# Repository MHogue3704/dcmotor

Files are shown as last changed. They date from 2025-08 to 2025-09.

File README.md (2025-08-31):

# ESP32 DC Motor Controller with OLED Interface

This project is a sophisticated motor controller for a 12V DC motor, built using an ESP32 microcontroller. It features a user-friendly interface with an SH1106 OLED display and a rotary encoder for precise speed adjustments, making it ideal for applications requiring fine-tuned motor control.

## Features

*   **Precise Speed Control:** Utilizes PWM to adjust the motor's speed from 0% to 100%.
*   **OLED Display Interface:** A 1.3-inch SH1106 OLED screen displays the motor's status (ON/OFF) and current speed.
*   **Rotary Encoder Input:** A rotary encoder with a push-button allows for intuitive speed adjustments and control.
*   **Save & Revert Speed Settings:** A "Confirm" button saves the desired speed, while a "Back" button reverts to the previously saved setting.
*   **Robust Motor Driver:** Employs the L298N H-Bridge to safely and efficiently drive the DC motor.
*   **Built with PlatformIO:** The project is configured for the PlatformIO IDE, ensuring easy dependency management and compilation.

## Hardware Components

| Component | Purpose |
| --- | --- |
| ESP32 Development Board | Main microcontroller for logic and control. |
| L298N H-Bridge Motor Driver | Drives the high-current DC motor. |
| 12V DC Geared Motor (e.g., 3 RPM) | The motor being controlled. |
| SH1106 1.3" OLED Module with Encoder | User interface for display and input. |
| CA-1235 Buck Converter Module | Steps down 12V to 5V for the ESP32. |
| 12V DC Power Supply | Powers the L298N driver and the motor. |
| Jumper Wires | For making connections. |

## Wiring Instructions

This project requires wiring for both the motor driver and the OLED display module. Detailed, step-by-step guides for each are provided in the repository:

*   **For the L298N Motor Driver:** Please refer to the [**`WIRING.md`**](./WIRING.md) file.
*   **For the SH1106 OLED Module:** Please refer to the [**`OLED_WIRING.md`**](./OLED_WIRING.md) file.

**Crucial:** Ensure you have a common ground (`GND`) connection between the ESP32-C3, the L298N module, and the OLED module for stable operation.

## Software Setup & Installation

This project is managed using PlatformIO.

1.  **Install PlatformIO:** If you haven't already, install [PlatformIO IDE for VS Code](https://platformio.org/install/ide?install=vscode).
2.  **Clone the Repository:**
    ```bash
    git clone https://github.com/MHogue3704/dcmotor.git
    cd dcmotor
    ```
3.  **Open in PlatformIO:** Open the cloned folder in VS Code with the PlatformIO extension installed.
4.  **Build & Upload:** PlatformIO will automatically detect the `platformio.ini` file and download the required libraries (`U8g2`, `RotaryEncoder`, `OneButton`). Once the dependencies are installed, build and upload the project to your ESP32.

## How to Use

Once the hardware is wired and the firmware is uploaded, the controller is ready to use:

1.  **Power On:** Connect the ESP32 via USB and turn on the 12V power supply for the motor.
2.  **View Display:** The OLED screen will light up, showing the motor status and speed.
3.  **Adjust Speed:** Turn the rotary encoder knob to increase or decrease the motor speed. The display will show `(Unsaved)` to indicate the change is temporary.
4.  **Save Speed:** Press the **"Confirm"** button to save the new speed. The `(Unsaved)` message will disappear.
5.  **Revert Speed:** If you make an adjustment you don't want, press the **"Back"** button to revert to the last saved speed.
6.  **Toggle Motor:** Click the **rotary encoder's built-in button** to toggle the motor ON or OFF.

## Code Overview

The main logic is contained in `src/main.cpp`:

*   **Pin Definitions:** All GPIO pin assignments for the motor and OLED module are at the top of the file.
*   **`setup()`:** Initializes serial communication, pin modes, PWM channels, the OLED display, and button handlers.
*   **`loop()`:** Continuously checks for input from the encoder and buttons.
*   **`drawScreen()`:** Renders the user interface on the OLED display.
*   **`updateMotor()`:** Applies the current speed value to the motor via PWM.
*   **Input Handlers (`checkEncoder`, `handle...Click`)**: These functions process input from the rotary encoder and buttons to modify the motor's state.




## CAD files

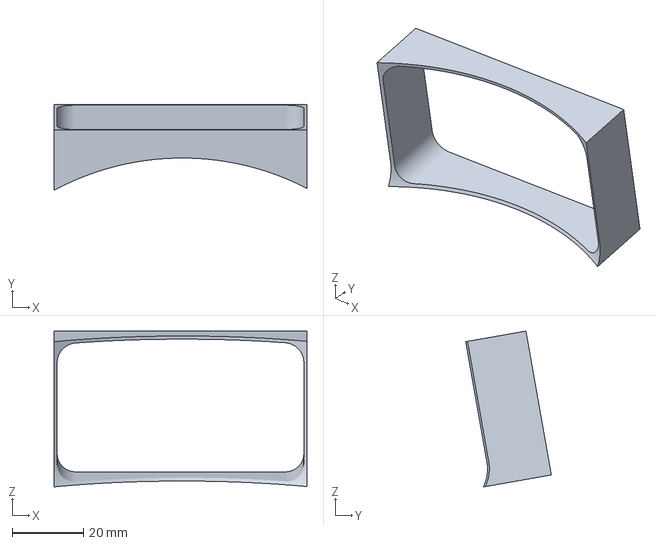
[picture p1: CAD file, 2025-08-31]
stl/controlbox.3mf
71.0 x 24.0 x 43.7 mm

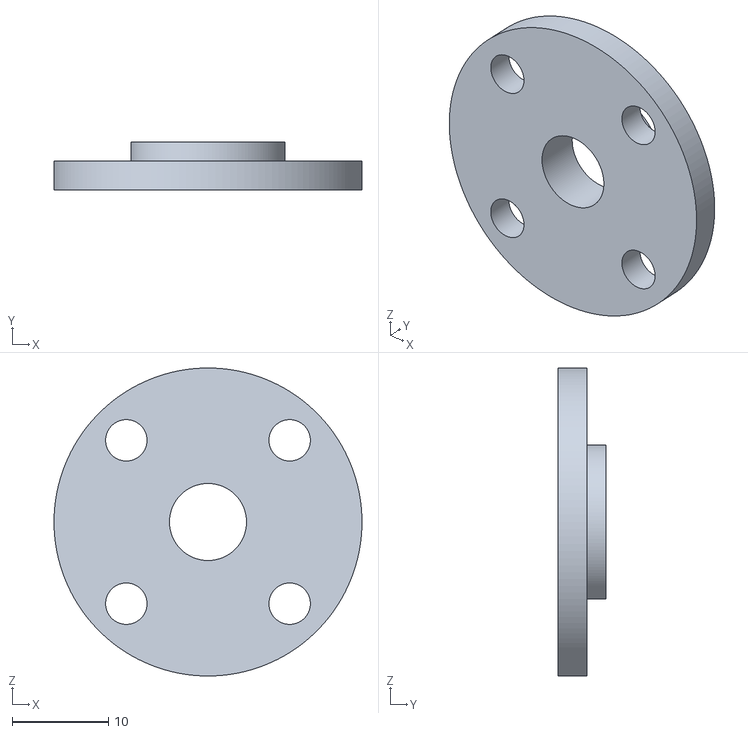
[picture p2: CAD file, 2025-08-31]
stl/Top_Cnter_Cap.stl
32.0 x 5.00 x 32.0

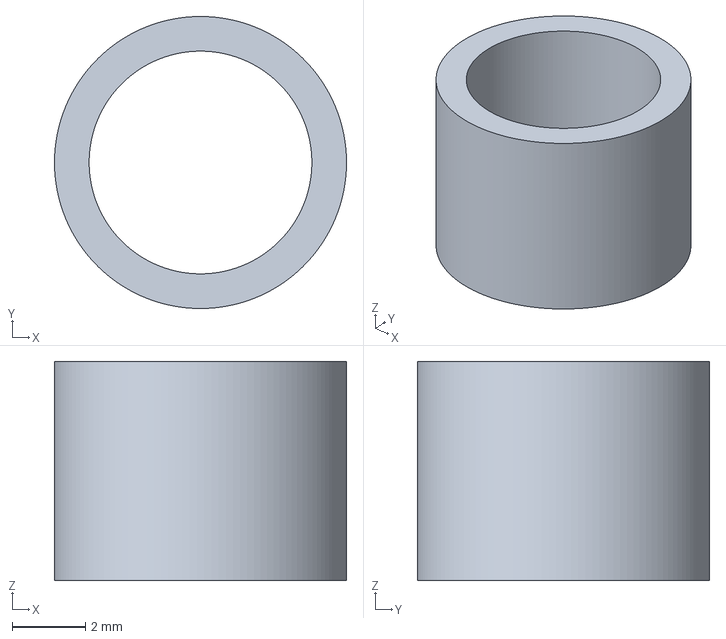
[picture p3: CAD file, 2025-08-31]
stl/motorbushing.3mf
8.00 x 8.00 x 6.00 mm

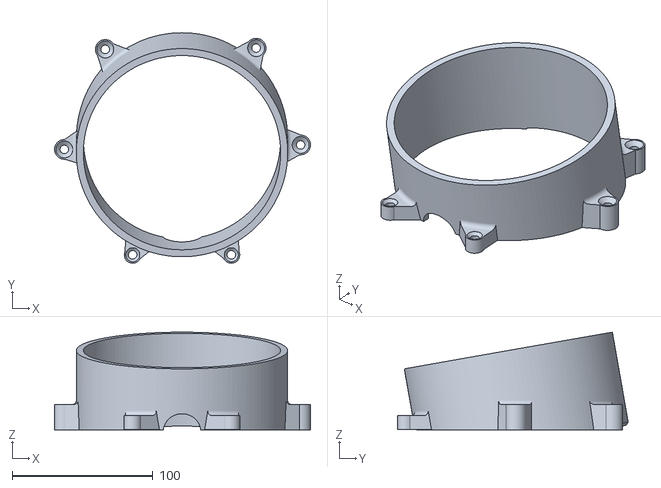
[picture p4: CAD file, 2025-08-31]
stl/CaseBottomV2.stl
181.7 x 163.6 x 69.3

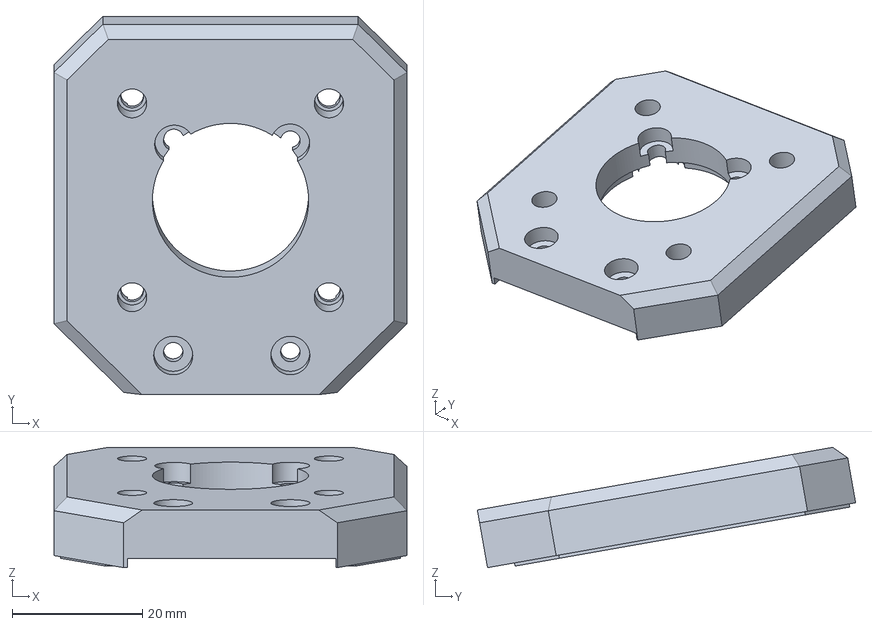
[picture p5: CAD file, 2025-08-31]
stl/stepperbodyconversion.3mf
54.2 x 58.1 x 18.5 mm

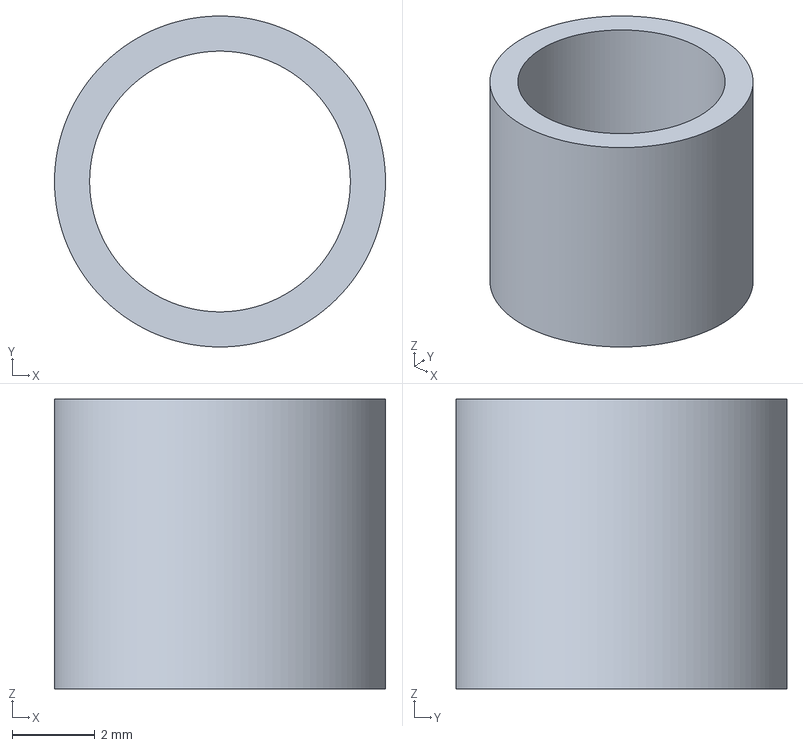
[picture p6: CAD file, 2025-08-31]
stl/bushin.3mf
8.00 x 8.00 x 7.00 mm

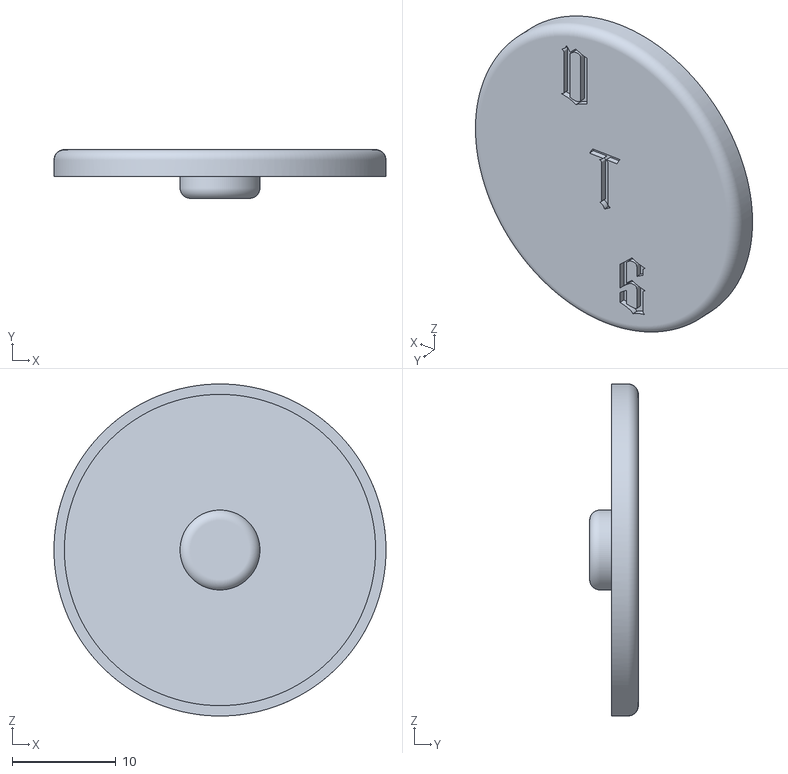
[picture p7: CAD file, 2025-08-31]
stl/Cnter_Cap.stl
32.0 x 4.70 x 32.0

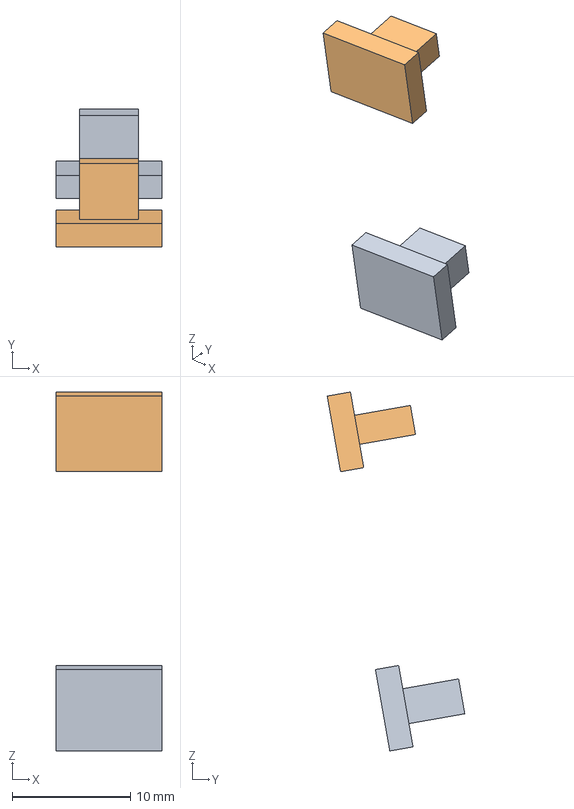
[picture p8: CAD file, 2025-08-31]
stl/buttons.3mf
9.00 x 11.6 x 30.4 mm
button
button_(2)

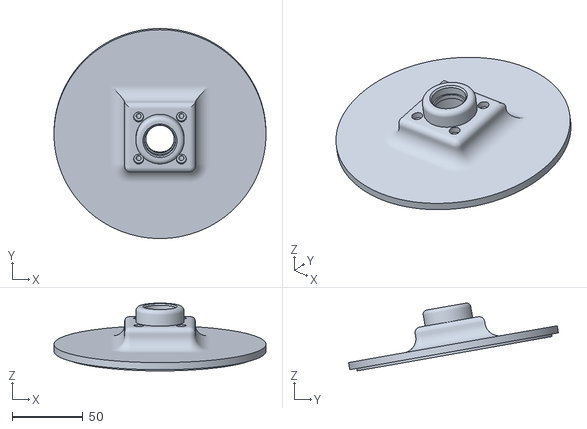
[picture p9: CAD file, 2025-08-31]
stl/Case_top.stl
150.0 x 148.6 x 48.0

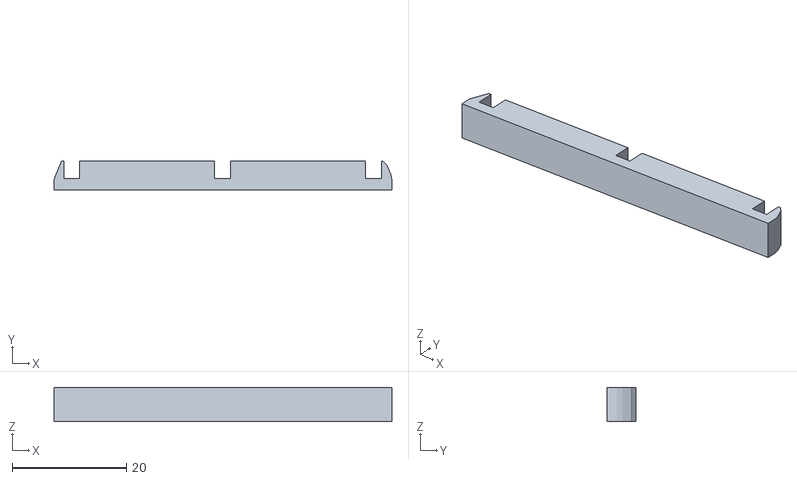
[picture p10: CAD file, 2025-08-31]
stl/boardSpacers.stl
59.1 x 5.00 x 6.00

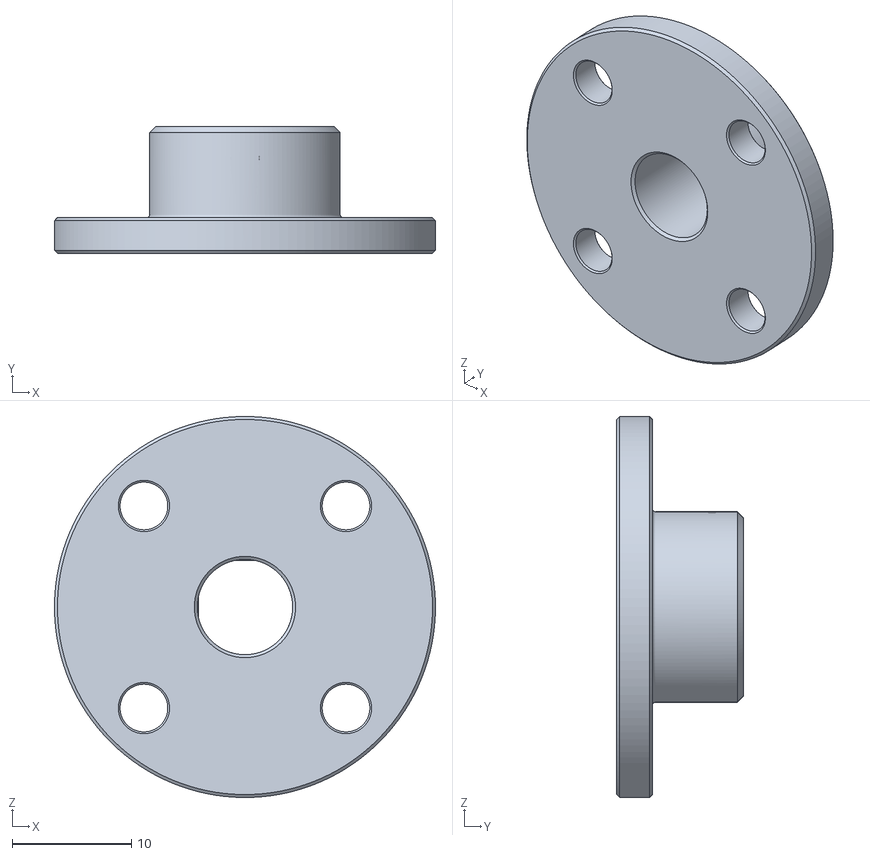
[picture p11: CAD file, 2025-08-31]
stl/boardSpacers_centers.stl
32.0 x 10.6 x 32.0

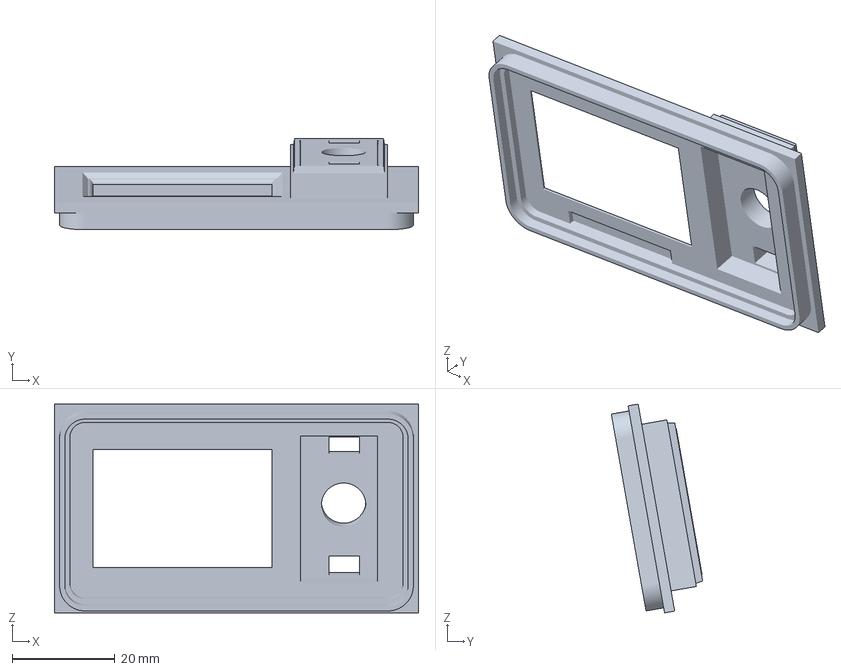
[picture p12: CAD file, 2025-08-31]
stl/controlface.3mf
71.0 x 17.8 x 40.7 mm

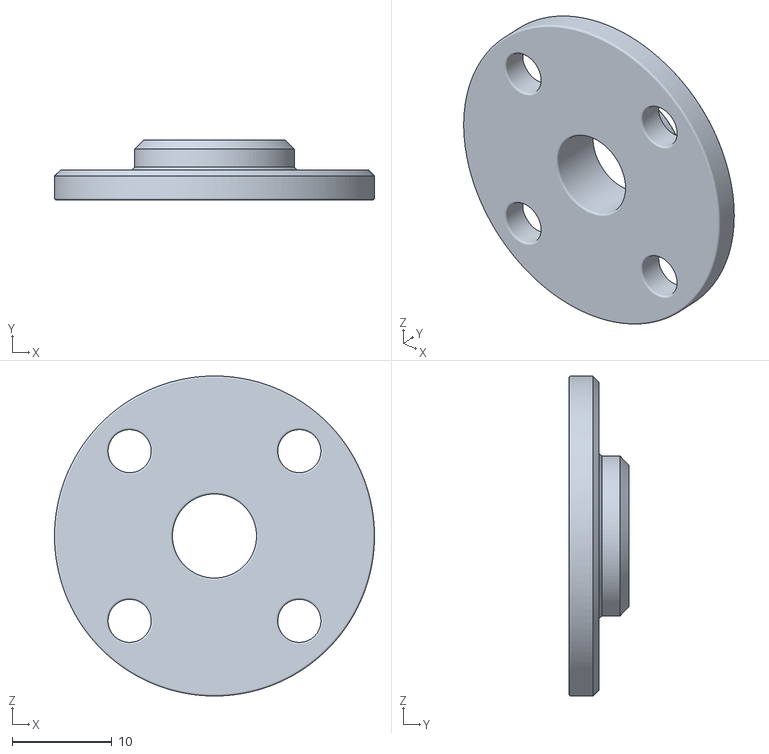
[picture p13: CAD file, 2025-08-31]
stl/boardSpacers_bottom.stl
32.0 x 6.00 x 32.0

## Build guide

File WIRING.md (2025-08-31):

# Wiring Guide: ESP32 with L298N DC Motor Driver

This guide details how to connect your ESP32 to an L298N H-Bridge module to control a 12V DC motor.

## Components

*   ESP32 Development Board
*   L298N H-Bridge Motor Driver Module
*   12V DC Motor
*   12V Power Supply for the motor
*   Jumper Wires

## Wiring Connections

### 1. L298N Power Connections

The L298N needs power for both its internal logic and the motor.

*   **L298N `+12V` Terminal** → **12V Power Supply `+` (Positive)**
*   **L298N `GND` Terminal** → **12V Power Supply `-` (Negative)** AND **ESP32 `GND` Pin** (this is crucial for a common ground reference).
*   **L298N `+5V` Terminal**: This is typically an *output* if the jumper next to it is in place. Do not connect anything here for now.

**L298N Jumper:**
*   The L298N module has a jumper (often labeled `5V_EN` or similar). **Keep this jumper on.** This enables the onboard 7805 voltage regulator, which creates 5V for the L298N's logic from your 12V motor supply.

### 2. Control Signal Connections (ESP32 to L298N)

These pins control the motor's speed and direction.

*   **ESP32 `GPIO13`** → **L298N `IN1`** (Motor Direction Pin 1)
*   **ESP32 `GPIO12`** → **L298N `IN2`** (Motor Direction Pin 2)
*   **ESP32 `GPIO14`** → **L298N `ENA`** (Motor Speed Control - PWM)

*Note: We are using Motor A outputs. If you were using Motor B, you would use `IN3`, `IN4`, and `ENB`.*

### 3. Motor Connections (L298N to DC Motor)

*   **L298N `OUT1` Terminal** → **DC Motor Terminal 1**
*   **L298N `OUT2` Terminal** → **DC Motor Terminal 2**

*If the motor spins in the opposite direction of what you expect, simply swap the wires on `OUT1` and `OUT2`.*

## Summary Diagram

```
// Power
12V PSU (+) -------> L298N +12V
12V PSU (-) -------> L298N GND
                  |
                  '-> ESP32 GND

// Control Signals
ESP32 GPIO13 ----> L298N IN1
ESP32 GPIO12 ----> L298N IN2
ESP32 GPIO14 ----> L298N ENA

// Motor
L298N OUT1 --------> DC Motor
L298N OUT2 --------> DC Motor
```
flowchart TD
    PSU[12V Power Supply]
    Buck[CA-1235 Buck Converter]
    ESP32[ESP32 Development Board]
    L298N[L298N Motor Driver]
    Motor[12V DC Motor]
    OLED[SH1106 OLED Module]
    Encoder[Rotary Encoder (on OLED Module)]

    %% Power Distribution
    PSU -- +12V --> L298N
    PSU -- +12V --> Buck
    PSU -- GND --> L298N
    PSU -- GND --> Buck

    Buck -- 5V --> ESP32
    Buck -- GND --> ESP32

    %% Motor Driver Wiring
    ESP32 -- GPIO13 --> L298N_IN1["L298N IN1"]
    ESP32 -- GPIO12 --> L298N_IN2["L298N IN2"]
    ESP32 -- GPIO14 --> L298N_ENA["L298N ENA"]
    L298N -- OUT1 --> Motor
    L298N -- OUT2 --> Motor

    %% OLED & Encoder Wiring
    ESP32 -- 3V3 --> OLED
    ESP32 -- GND --> OLED
    ESP32 -- GPIO22 --> OLED_SCL["OLED SCL"]
    ESP32 -- GPIO21 --> OLED_SDA["OLED SDA"]
    ESP32 -- GPIO25 --> OLED_TRA["Encoder TRA"]
    ESP32 -- GPIO26 --> OLED_TRB["Encoder TRB"]
    ESP32 -- GPIO27 --> OLED_PSH["Encoder PSH"]
    ESP32 -- GPIO32 --> OLED_BAK["OLED BAK"]
    ESP32 -- GPIO33 --> OLED_CON["OLED CON"]

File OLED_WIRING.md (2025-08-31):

# Wiring Guide: ESP32 with SH1106 OLED & Rotary Encoder Module

This guide details how to connect your ESP32 to the SH1106 OLED module with an integrated rotary encoder.

## Components

*   ESP32 Development Board
*   SH1106 OLED Module with Rotary Encoder
*   Jumper Wires

## Pinout Identification

The pins on your module are labeled as follows:
`VCC`, `GND`, `SCL`, `SDA`, `TRB`, `TRA`, `PSH`, `BAK`, `CON`

*   **VCC/GND**: Power pins.
*   **SCL/SDA**: I2C communication pins for the display.
*   **TRA/TRB**: Rotary encoder pins A and B.
*   **PSH**: Rotary encoder push-button.
*   **BAK**: "Back" button.
*   **CON**: "Confirm" button.

## Wiring Connections

Connect the pins from the OLED module to your ESP32 as follows. These pins are chosen to avoid conflict with the motor driver pins.

*   **OLED `VCC`** → **ESP32 `3V3`**
*   **OLED `GND`** → **ESP32 `GND`**
*   **OLED `SCL`** → **ESP32 `GPIO22`** (I2C Clock)
*   **OLED `SDA`** → **ESP32 `GPIO21`** (I2C Data)
*   **OLED `TRA`** → **ESP32 `GPIO25`** (Encoder Pin A)
*   **OLED `TRB`** → **ESP32 `GPIO26`** (Encoder Pin B)
*   **OLED `PSH`** → **ESP32 `GPIO27`** (Encoder Push Button)
*   **OLED `BAK`** → **ESP32 `GPIO32`** (Back Button)
*   **OLED `CON`** → **ESP32 `GPIO33`** (Confirm Button)

## Summary Diagram

```
ESP32                   SH1106 Module
--------                -------------
  3V3  ────────────────→   VCC
  GND  ────────────────→   GND
GPIO22 ────────────────→   SCL
GPIO21 ────────────────→   SDA
GPIO25 ────────────────→   TRA
GPIO26 ────────────────→   TRB
GPIO27 ────────────────→   PSH
GPIO32 ────────────────→   BAK
GPIO33 ────────────────→   CON
```

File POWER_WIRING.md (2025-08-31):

# Power Distribution Wiring Guide

This guide explains how to power all components (ESP32, L298N, and OLED) from a single 12V power supply using a CA-1235 buck converter. This setup is essential for a stable, self-contained project without relying on USB power for the microcontroller.

## Components

*   **12V DC Power Supply:** The main power source for the entire project.
*   **CA-1235 Buck Converter:** A step-down module to convert 12V from the power supply into a stable 5V for the ESP32.
*   **ESP32-C3, L298N, OLED Module:** The core components of the project.

## Step 1: Set the Buck Converter to 5V

**CRITICAL STEP:** Before connecting the buck converter to your ESP32, you MUST ensure its output is set to 5V.

1.  **Connect Input:** Connect your 12V power supply to the `IN+` and `IN-` terminals of the CA-1235 module.
2.  **Measure Output:** Use a multimeter to measure the voltage across the `OUT+` and `OUT-` terminals.
3.  **Adjust (if necessary):** The CA-1235 often has solder pads or a potentiometer to select the output voltage. Adjust it until your multimeter reads **5V**. If it's already fixed at 5V, confirm this reading.
4.  **Disconnect Power:** Once confirmed, disconnect the 12V power supply.

**Do not proceed until you have confirmed a stable 5V output.**

## Step 2: Wiring Diagram

The goal is to distribute power from the 12V supply to the L298N directly and to the ESP32/OLED via the 5V buck converter.

1.  **12V Power Supply to Components:**
    *   **PSU `+` (Positive)** → Connect to **both**:
        *   L298N `+12V` terminal.
        *   CA-1235 `IN+` terminal.
    *   **PSU `-` (Negative/GND)** → Connect to **both**:
        *   L298N `GND` terminal.
        *   CA-1235 `IN-` terminal.

2.  **Buck Converter (5V Out) to ESP32:**
    *   **CA-1235 `OUT+`** → **ESP32 `5V` pin**.
    *   **CA-1235 `OUT-`** → **ESP32 `GND` pin**.

3.  **Common Ground:**
    *   A common ground is essential. By connecting the 12V PSU's negative line to both the L298N and the buck converter's input, and the buck converter's output ground to the ESP32, all components will share the same ground reference.

## Summary Diagram

```
                      +---------------------+
12V PSU (+) --------->| L298N +12V          |
                      |                     |
                      +---------------------+

                      +---------------------+
12V PSU (+) --------->| CA-1235 IN+         |
                      |         OUT+ (5V) --+--> ESP32 (5V Pin)
                      |                     |
12V PSU (-) --+------>| CA-1235 IN-         |
              |       |         OUT- (GND)--+--> ESP32 (GND Pin)
              |       +---------------------+
              |
              |       +---------------------+
              +------>| L298N GND           |
                      |                     |
                      +---------------------+
```

The OLED display is powered by the ESP32's 3.3V regulator, so its wiring does not change. By powering the ESP32 through its `5V` pin, its onboard regulator will provide the `3.3V` needed for the OLED and its own logic.

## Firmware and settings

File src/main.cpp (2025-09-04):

#include <Arduino.h>
#include <Wire.h>
#include <U8g2lib.h>
#include <RotaryEncoder.h>
#include <OneButton.h>

// --- Pin Definitions ---

// L298N Motor Driver Pins
const int MOTOR_IN1 = 13;
const int MOTOR_IN2 = 12;
const int MOTOR_ENA = 14;

// SH1106 OLED & Encoder Module Pins
const int OLED_SCL = 22;
const int OLED_SDA = 21;
const int ENC_A = 25;
const int ENC_B = 26;
const int ENC_BTN = 27;
const int BACK_BTN = 32;
const int CONFIRM_BTN = 33;

// --- PWM Configuration ---
const int PWM_CHANNEL = 0;
const int PWM_FREQUENCY = 5000;
const int PWM_RESOLUTION = 8; // 0-255

// --- Global Variables ---
int motorSpeed = 65; // Current PWM value (0-255)
int savedSpeed = 65; // Speed that is "confirmed"
bool motorRunning = true;
const int MIN_SPEED = 0;
const int MAX_SPEED = 255;

// --- Object Declarations ---

// Onboard OLED (SSD1306 or SH1106)
// Example: onboard SSD1306 at 0x3C, external SH1106 at 0x3C or 0x3D
#include <U8g2lib.h>
U8G2_SH1106_128X64_NONAME_F_HW_I2C sh1106_u8g2(U8G2_R0, /* reset=*/ U8X8_PIN_NONE); // External SH1106
// U8G2_SSD1306_128X64_NONAME_F_HW_I2C onboard_u8g2(U8G2_R0, /* reset=*/ U8X8_PIN_NONE); // Onboard OLED (change type if needed)

// Rotary Encoder
RotaryEncoder encoder(ENC_A, ENC_B, RotaryEncoder::LatchMode::FOUR0);

// Buttons
OneButton encoderButton(ENC_BTN, true); // 'true' for active low
OneButton backButton(BACK_BTN, true);
OneButton confirmButton(CONFIRM_BTN, true);

// --- Function Prototypes ---
void drawOnboardScreen();
void drawSH1106Screen();
void updateMotor();
void checkEncoder();
void handleEncoderClick();
void handleBackClick();
void handleConfirmClick();
void handleLongPressConfirm();

unsigned long totalRunTimeMs = 0;
unsigned long lastRunUpdate = 0;

void setup() {
  // Enable internal pull-ups for rotary encoder pins
  pinMode(ENC_A, INPUT_PULLUP);
  pinMode(ENC_B, INPUT_PULLUP);
  Serial.begin(115200);
  Serial.println("Motor Controller with OLED Initializing...");

  // Motor Pin Setup
  pinMode(MOTOR_IN1, OUTPUT);
  pinMode(MOTOR_IN2, OUTPUT);
  digitalWrite(MOTOR_IN1, HIGH); // Set direction forward
  digitalWrite(MOTOR_IN2, LOW);

  // PWM Setup
  ledcSetup(PWM_CHANNEL, PWM_FREQUENCY, PWM_RESOLUTION);
  ledcAttachPin(MOTOR_ENA, PWM_CHANNEL);

  // I2C and Display Setup
  Wire.begin(OLED_SDA, OLED_SCL);
  // Removed onboard OLED initialization
  if (!sh1106_u8g2.begin()) {
    Serial.println("SH1106 OLED init failed!");
    while (1);
  }
  sh1106_u8g2.setFont(u8g2_font_ncenB08_tr);

  // Button Setup
  encoderButton.attachClick(handleEncoderClick);
  backButton.attachClick(handleConfirmClick); // Now increases speed
  confirmButton.attachClick(handleBackClick); // Now decreases speed
  backButton.attachLongPressStart(handleLongPressConfirm);
  confirmButton.attachLongPressStart(handleLongPressConfirm);

  // Initial State
  updateMotor();
  // Removed drawOnboardScreen call
  drawSH1106Screen();

  Serial.println("Initialization complete.");
}

void loop() {
  // Check for inputs
  checkEncoder();
  encoderButton.tick();
  backButton.tick();
  confirmButton.tick();

  // Update running time if motor is running
  if (motorRunning) {
    unsigned long now = millis();
    if (lastRunUpdate == 0) lastRunUpdate = now;
    totalRunTimeMs += (now - lastRunUpdate);
    lastRunUpdate = now;
  } else {
    lastRunUpdate = millis();
  }

  // Removed drawOnboardScreen call
  drawSH1106Screen();
  // Removed delay for maximum encoder polling frequency
}

// --- Core Functions ---

// Removed drawOnboardScreen function

void drawSH1106Screen() {
  sh1106_u8g2.clearBuffer();
  sh1106_u8g2.drawStr(0, 10, "Motor Speed Control");
  sh1106_u8g2.drawHLine(0, 14, 128);

  // Motor Status
  sh1106_u8g2.drawStr(0, 30, "Status:");
  sh1106_u8g2.drawStr(50, 30, motorRunning ? "ON" : "OFF");

  // Speed Value
  sh1106_u8g2.drawStr(0, 45, "Speed:");
  char speedStr[5];
  sprintf(speedStr, "%d", motorSpeed);
  sh1106_u8g2.drawStr(50, 45, speedStr);

  // Display saved speed if different
  if (motorSpeed != savedSpeed) {
    sh1106_u8g2.drawStr(80, 45, "(Unsaved)");
  }

  // Instructions
  sh1106_u8g2.drawStr(0, 60, "Click knob=On/Off | CON=Save");

  sh1106_u8g2.sendBuffer();
}

void updateMotor() {
  if (motorRunning) {
    ledcWrite(PWM_CHANNEL, motorSpeed);
    Serial.print("[DEBUG] ledcWrite PWM_CHANNEL: ");
    Serial.print(PWM_CHANNEL);
    Serial.print(", motorSpeed: ");
    Serial.println(motorSpeed);
  } else {
    ledcWrite(PWM_CHANNEL, 0);
    Serial.print("[DEBUG] ledcWrite PWM_CHANNEL: ");
    Serial.print(PWM_CHANNEL);
    Serial.println(", motorSpeed: 0 (OFF)");
  }
  Serial.print("Motor state: ");
  Serial.print(motorRunning ? "ON" : "OFF");
  Serial.print(", Speed PWM: ");
  Serial.println(motorSpeed);
  Serial.print("[DEBUG] MOTOR_IN1: ");
  Serial.print(digitalRead(MOTOR_IN1));
  Serial.print(", MOTOR_IN2: ");
  Serial.println(digitalRead(MOTOR_IN2));
}

// --- Input Handling ---

void checkEncoder() {
  static int lastPos = 0;
  static unsigned long lastChange = 0;
  const unsigned long debounceMs = 5; // 5ms debounce
  encoder.tick();
  int newPos = encoder.getPosition();

  if (newPos != lastPos) {
    unsigned long now = millis();
    if (now - lastChange > debounceMs) {
      if (newPos > lastPos) {
        motorSpeed = min(motorSpeed + 10, MAX_SPEED);
      } else {
        motorSpeed = max(motorSpeed - 10, MIN_SPEED);
      }
      lastPos = newPos;
      lastChange = now;
      updateMotor(); // Update motor speed immediately on change
      Serial.print("Encoder position: ");
      Serial.print(newPos);
      Serial.print(" | Motor speed: ");
      Serial.println(motorSpeed);
    }
  }
}

void handleEncoderClick() {
  motorRunning = !motorRunning; // Toggle motor state
  Serial.println("Encoder button clicked. Toggling motor.");
  updateMotor();
}

void handleBackClick() {
  // Increase speed
  motorSpeed = min(motorSpeed + 10, MAX_SPEED);
  Serial.println("Back button clicked. Speed increased.");
  updateMotor();
}

void handleConfirmClick() {
  // Decrease speed
  motorSpeed = max(motorSpeed - 10, MIN_SPEED);
  Serial.println("Confirm button clicked. Speed decreased.");
  updateMotor();
}

void handleLongPressConfirm() {
  // Save the current speed
  savedSpeed = motorSpeed;
  Serial.println("Long press: Speed confirmed and saved.");
  // You could also save this to EEPROM/Preferences for persistence
}

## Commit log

2025-08-31 Initial commit: DC motor control with OLED display and rotary encoder
2025-08-31 docs: Add power wiring guide for CA-1235 buck converter
2025-08-31 feat: Update project for generic ESP32 board
2025-08-31 Update WIRING.md
    added flowchart
2025-08-31 Create STL
2025-08-31 Add files via upload
    added 3d bodies
    [CaseBottomV2.stl, Case_top.stl, Cnter_Cap.stl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]
2025-09-04 Finalize ESP32 SH1106 OLED, rotary encoder, and motor control logic with improved button and encoder handling
